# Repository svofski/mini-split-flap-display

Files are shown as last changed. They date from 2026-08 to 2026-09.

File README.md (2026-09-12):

# Mini Split-Flap Display

Video:

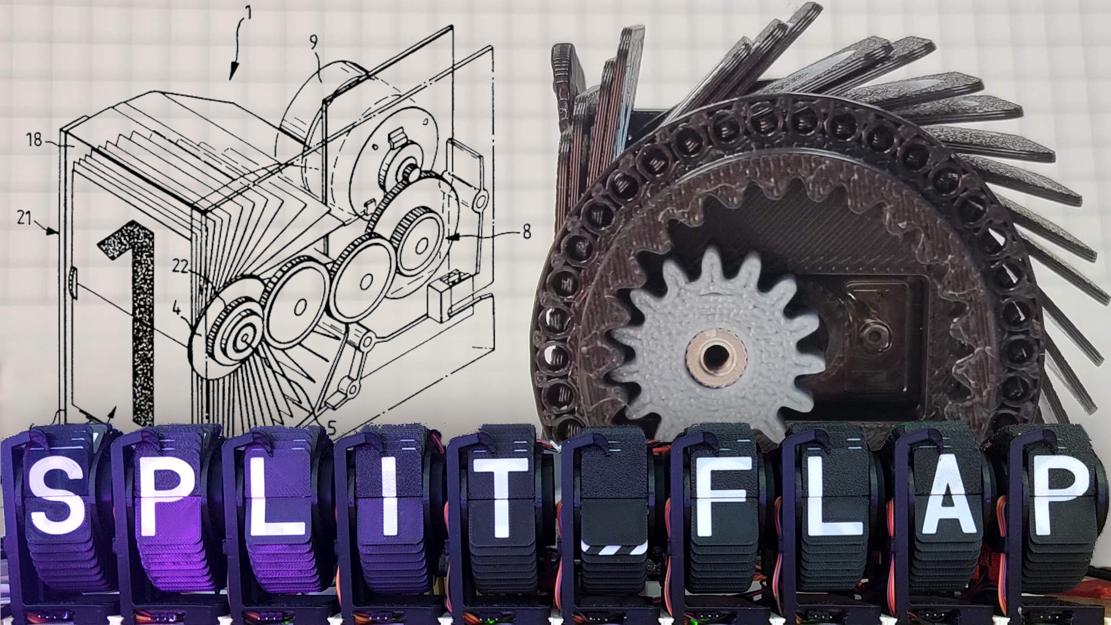
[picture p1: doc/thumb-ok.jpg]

https://www.youtube.com/watch?v=8y3peudQFPg

[Notes](doc/notes.txt), [printables](printables) and [CAD](printables/cad).

## Design goals

 * as compact as reasonably possible
 * full English alphabet and numbers, space and one extra character (38 flaps)
 * as cheap as reasonably possible, a bit janky is ok
 * 3D printable with minimal extra parts

The compact and cheap requirement limits the choice of motors to MG90S, or even SG90 micro servos. Steppers of similar size exist but they are a relative rarity and require a driver which costs more and takes space. Fortunately these motors can be bought in 360 degree variant.

## Approximate BOM

 * black and white PLA are mandatory for optical sensor contrast
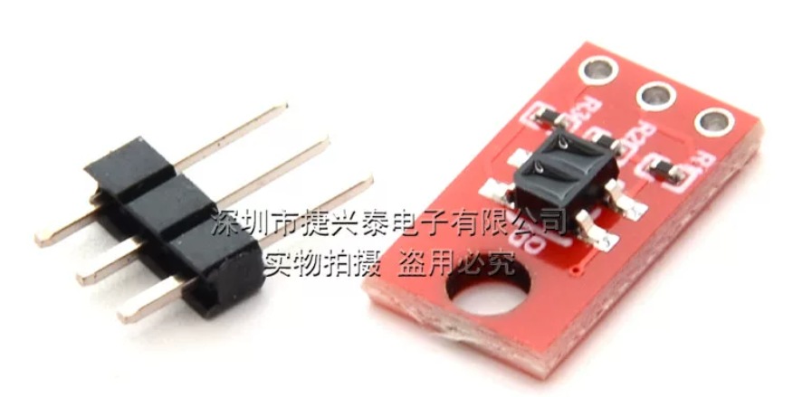
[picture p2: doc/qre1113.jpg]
qre1113
 * QRE1113 sensor module (1 per module, ￥1.89/pc)  (modules may require changing LED resistor to 330 ohm!)
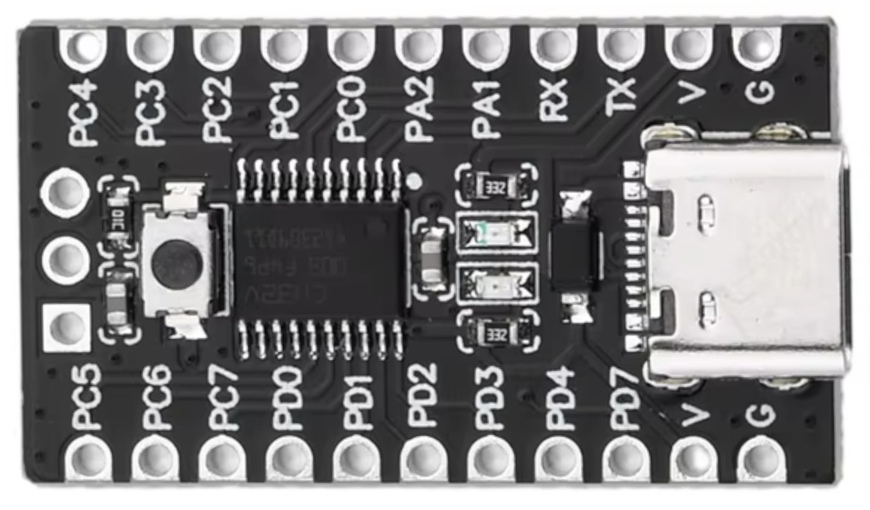
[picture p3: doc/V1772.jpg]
v1772
 * V1772 CH32V003F4P6 (1 per module, ￥2.86/pc) 
 * MG90S 360 degree servo (1 per module, ￥6.48/pc), SG90 360 degree can be used as well

## Design

See [printables](printables) and [CAD](printables/cad) for source files and detailed breakdown of every part.

The pictures tell everything. The motor is hidden inside the stator drum. Flappy drum sits on the stator driven by a little cog.
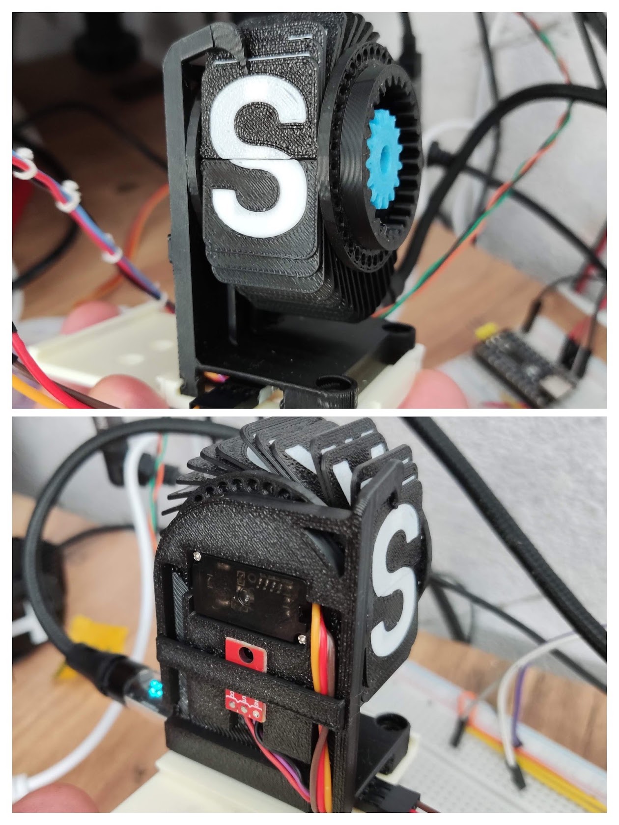
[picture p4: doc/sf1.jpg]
split-flap


The wires are relatively neatly tucked away in cable channels carved for them in the main post, held captive together with the sensor board with a little snap-fit bracket.
The MCU board is hidden in the foot. Some careful wire soldering is required during assembly which takes quite a long time.
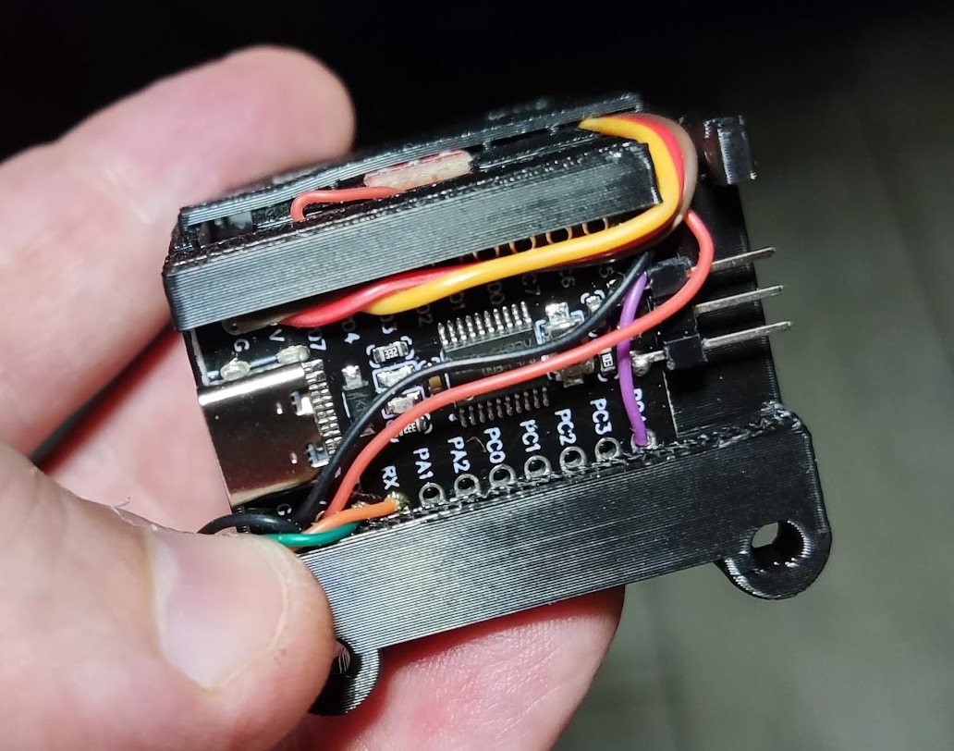
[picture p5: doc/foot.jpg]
feet pics


Because there are so many flaps in such a small place, precision positioning is important. The feedback is optical.
One of the sides of the flaps drum has embedded codewheel. Zero position is marked by a wider tick.
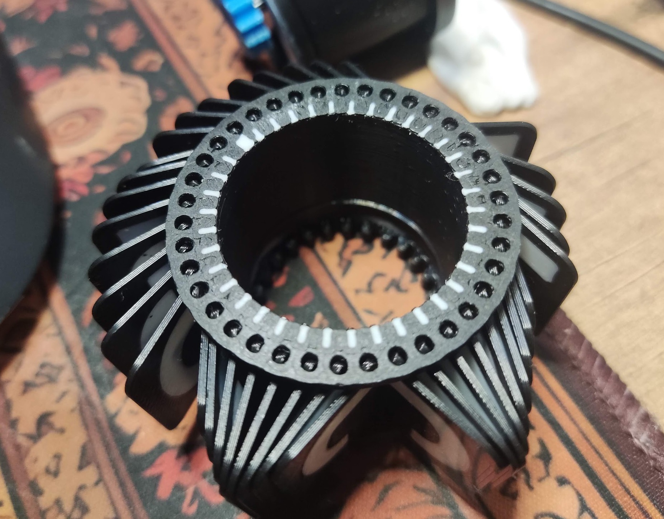
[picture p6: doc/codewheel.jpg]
codewheel


## Position sensing

Tracking reflective codewheel is not as trivial as I expected, sensor readout is far from ideal. Here's an example of what the readings look like:
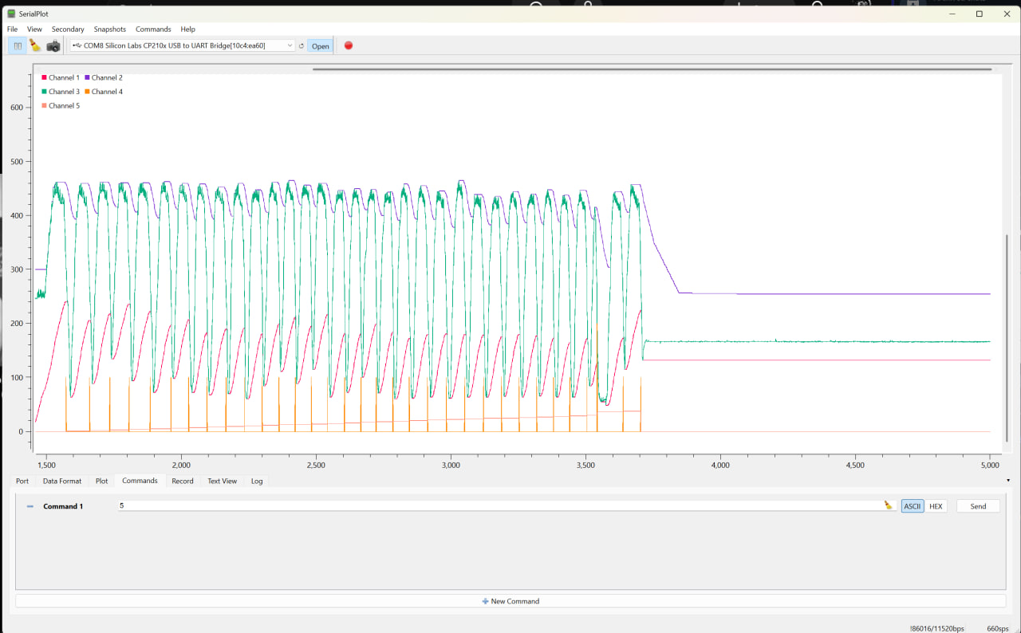
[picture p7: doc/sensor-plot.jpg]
sensor


The algorithm tracks min and max on raw data(green) independently (blue and red lines), then detects transitions over median line with added hysteresis.
High contrast here is very important. It's also important to print the code wheel side on a matte plate like Cool Plate SuperTack. Shiny tick marks read very poorly.

## Communications

Each wheel has independent controller (CH32V003). All together they are connected via I2C bus.

The master controller is Arduino Nano. In addition to requesting a letter display, the protocol supports setting I2C address and homing offset for every module.

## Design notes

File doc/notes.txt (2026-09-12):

Encoder sensor
~~~~~~~~~~~~~~
QRE1113 module 8x14.2mm, height ~3mm

Modifications for 5V operation

LED resistor: 330 ohm
collector resistor: 200K (maybe the default 100K is ok)

Split-Flap Controller
~~~~~~~~~~~~~~~~~~~~~
Controller board V1772, 5V MCU CH32V003F4P6

Schematic and notes: https://kyoichisato.github.io/ch32v003-getting-started-ja/V1772.html

Motors
~~~~~~
MG90S 360 degree version

Master MCU
~~~~~~~~~~
Arduino Nano 3 (5V)

Ideally same V1772 if both UART and I2C can be enabled at the same time. Definitely possible with ch32v003fun version, Arduino has too much fat.

Connections
~~~~~~~~~~~

Split-Flap module:

QRE1113 OUT -> CH32 PC4
MG90S PWM   -> CH32 PD3
I2C SDA	    -> CH32 PC1         -> Arduino Nano A4         -> 4K7 pullup to +5V      GREEN or BLUE
I2C SCL     -> CH32 PC2         -> Arduino Nano A5         -> 4K7 pullup to +5V      ORANGE

I2C Communication
~~~~~~~~~~~~~~~~~
Each split-flap display has its own address assigned at build/flashing time. Leftmost is 0x10, second to right is 0x11, etc.

EEPROM
~~~~~~

Reconfigurable parameters:

  - i2c address which must be unique for every display
  - zero mark offset (-4..-2 typically)
  - tracking divider, how fast min/max tracking decays

I2C Commands
~~~~~~~~~~~~

A-Z 0-9 - space	  display character
h                 home
q                 respond with "SFD" [addr] [homing offset] [position] [state] [tracking div]
z [n]             write new homing adjust, signed int8_t
r [n]             write new speed adjust, signed int8_t
d [n]             write new tracking divider (uint8_t), typically 64..110
a [addr] [~addr]  write new i2c addr, e.g.  0x61 0x11 0xee set addr = 0x11

Master controller (usb serial)
~~~~~~~~~~~~~~~~~~~~~~~~~~~~~~

Console commands: 

s               scan the bus, update internal structures and and print info about each display

p TEXT          type text on all units without power budgeting. guarranteed to fail if there are more than 2 units.

h               home all units with power budgeting

t TEXT          type text with power budgeting. text comprises [A-Z0-9\-] to display space use lowercase "h" (home), underscore to skip position

  t HELLO        type HELLO from current position  
  t _____X       update character in position 6 to X
  t h______      home display in position 1

Tuning commands

a addr          assign address. Only valid when there is a single display connected. Necessary when configuring a new module.
  a 0x11	set display i2c address = 0x11

z addr offset   set homing offset
  z 0x11 -3     display at 0x11 homes to position -3

d addr value    set envelope tracking divider (larger value means slower decay)
  d 0x11 110    set device 0x11 to track slower

r addr value    set speed offset. this value is multiplied by 8 and added to default speed programmed in display unit. the unit is microseconds/8.
  r 0x11 -10    add -80 to base speed

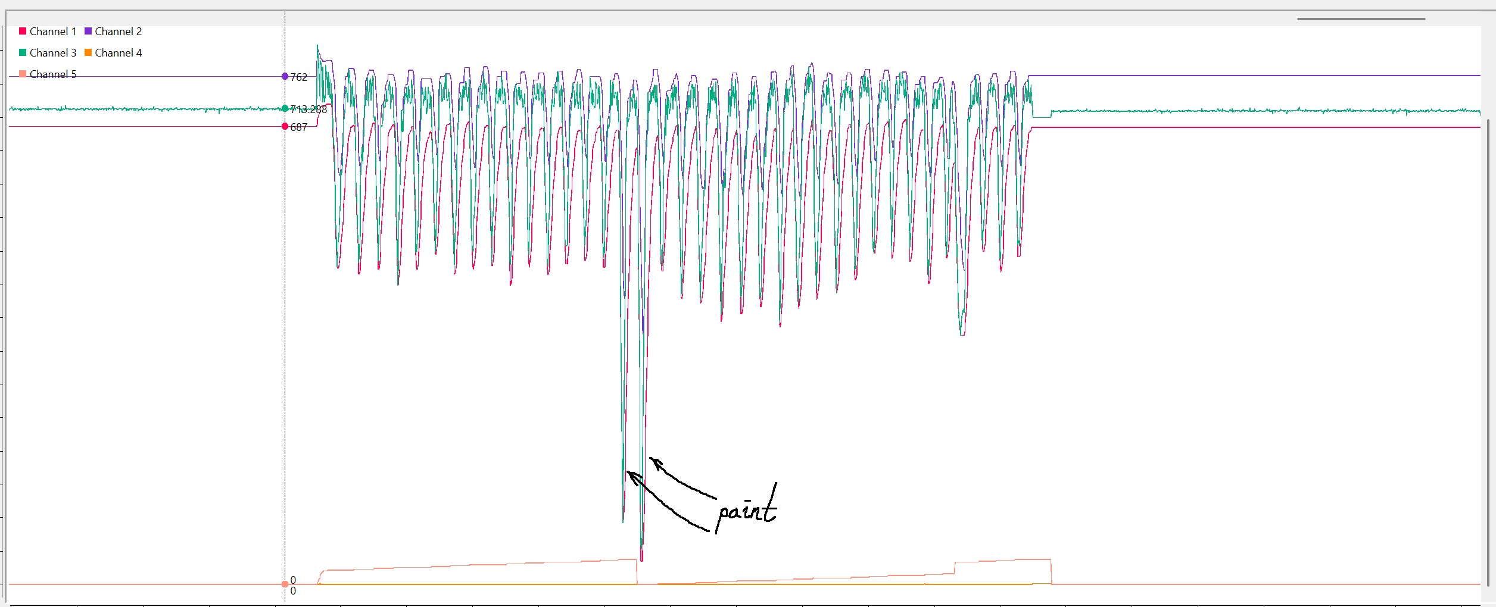
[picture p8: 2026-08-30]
doc/sensor-plot-white-paint.jpg

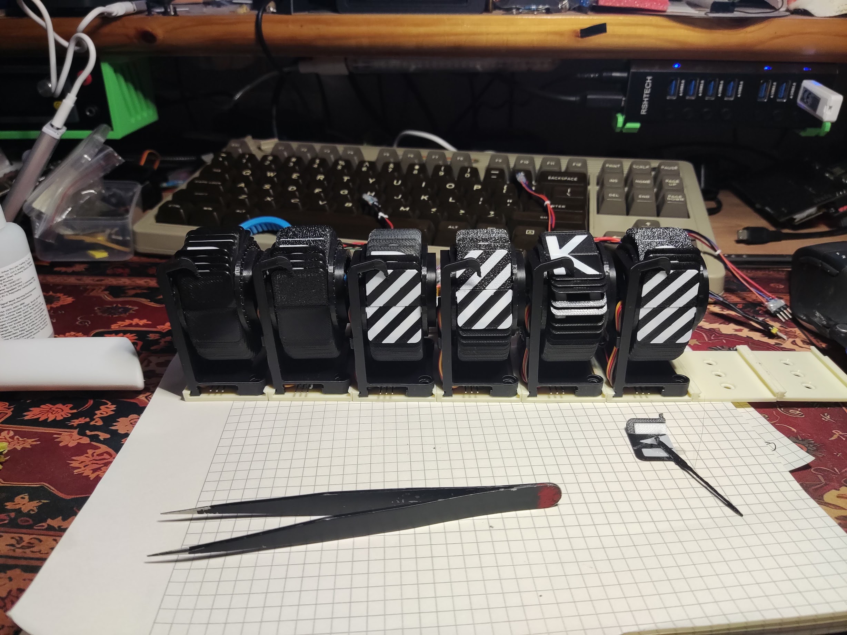
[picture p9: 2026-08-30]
doc/6pieces.jpg

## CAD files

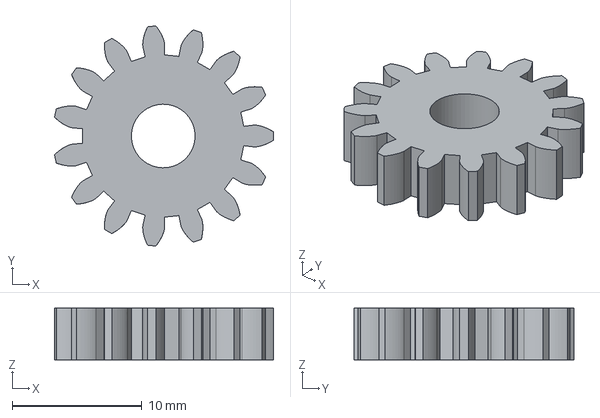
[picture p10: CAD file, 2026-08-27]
printables/cad/step/pinion.step
16.9 x 17.0 x 4.00 mm

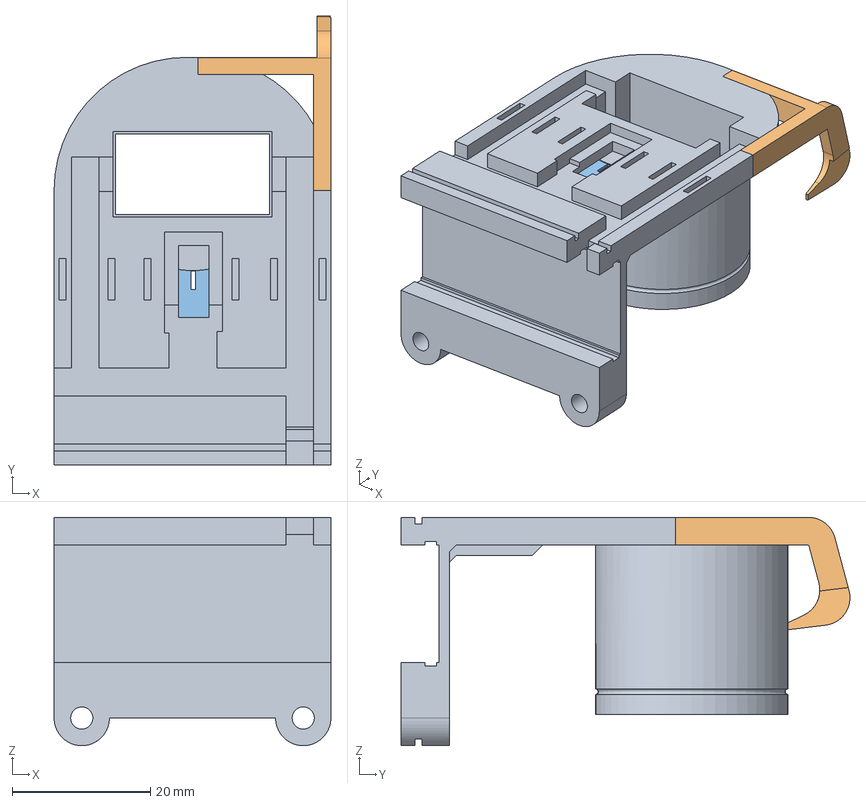
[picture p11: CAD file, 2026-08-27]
printables/cad/wheel-exp4-qre1113v3.FCStd
40.0 x 64.9 x 33.0 mm
Main
Finger
Aperture

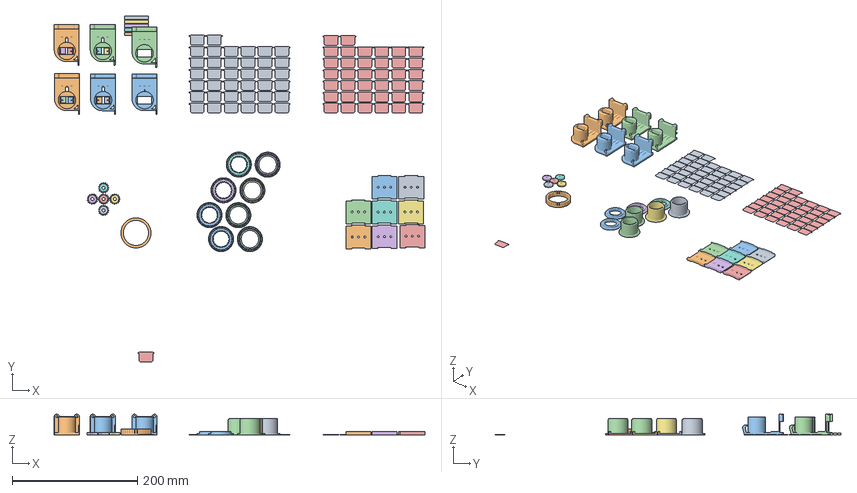
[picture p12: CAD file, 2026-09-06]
printables/split-flap-multiplate.3mf
591.3 x 551.9 x 33.0 mm
AssemblyJig
Assembly x 4
wheel-axle-markers-offset x 4
snappy-bracket.step x 5
stator_with_dovetail3.step x 2
rail.step x 8
pinion.step x 5
wheel-exp4-qre1113v3bis.step x 4
wheel-exp4-qre1113v3bis-aperture.step x 8

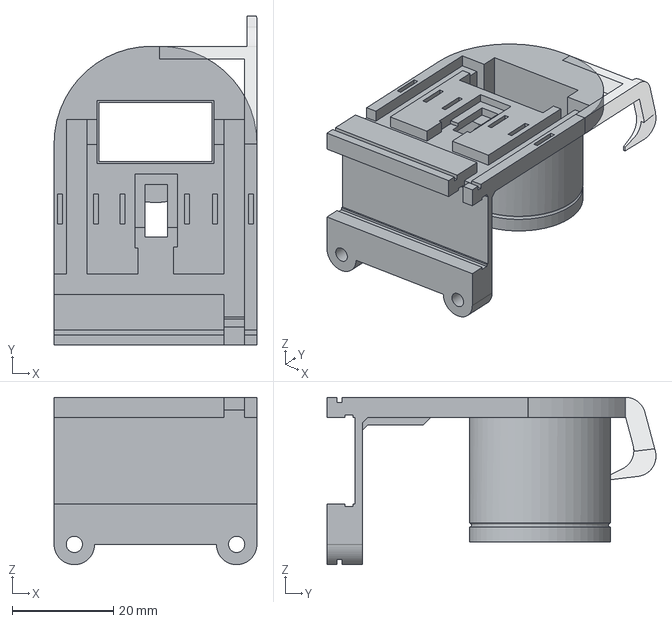
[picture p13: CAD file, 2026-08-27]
printables/cad/step/wheel-exp4-qre1113v3bis.step
40.0 x 64.9 x 33.0 mm
Main
Finger

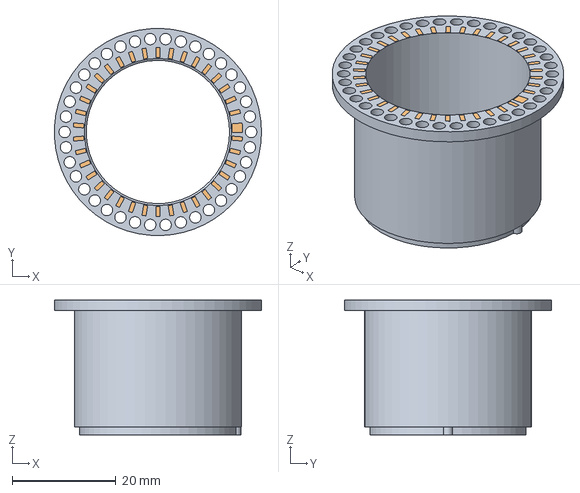
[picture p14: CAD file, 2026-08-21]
printables/cad/wheel-exp6.FCStd
40.0 x 40.0 x 26.0 mm
Wheel
MarkersWhite

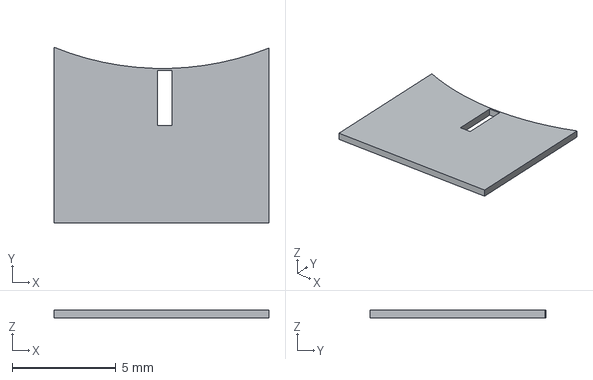
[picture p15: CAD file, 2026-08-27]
printables/cad/step/wheel-exp4-qre1113v3bis-aperture.step
10.4 x 8.48 x 0.4 mm

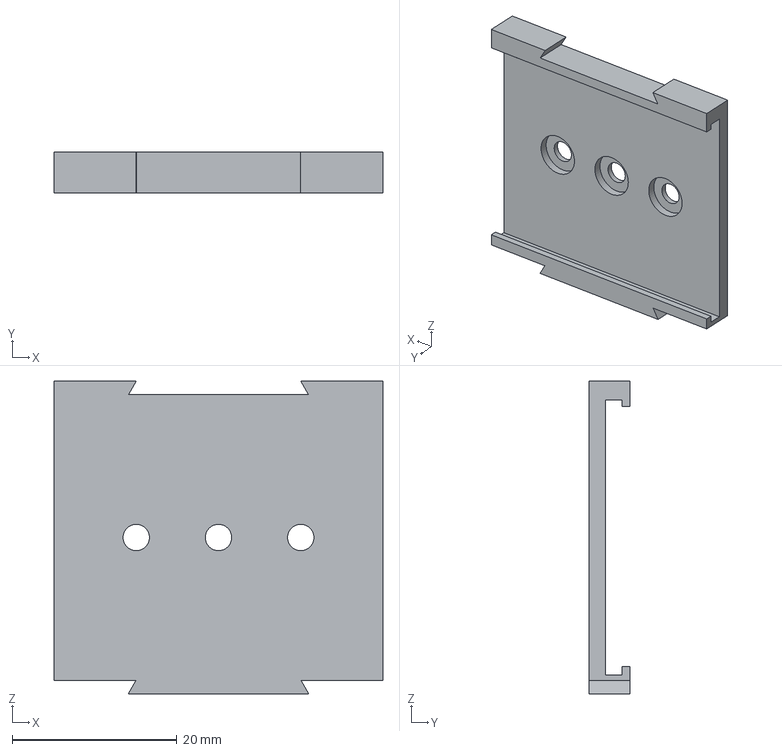
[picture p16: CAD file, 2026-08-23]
printables/cad/step/rail.step
40.0 x 5.00 x 38.0 mm

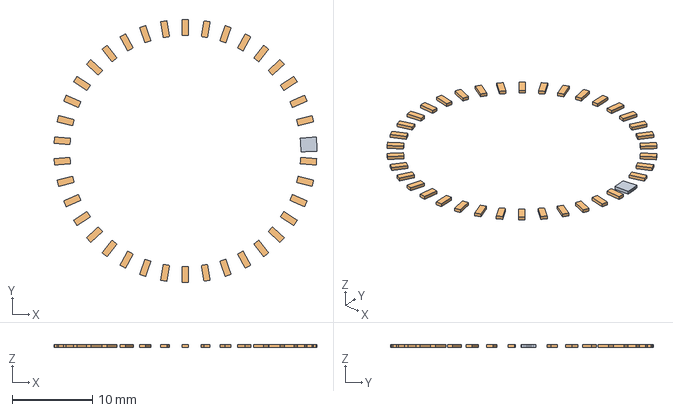
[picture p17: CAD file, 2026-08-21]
printables/cad/step/wheel-axle-markers-offset.step
32.7 x 32.7 x 0.4 mm

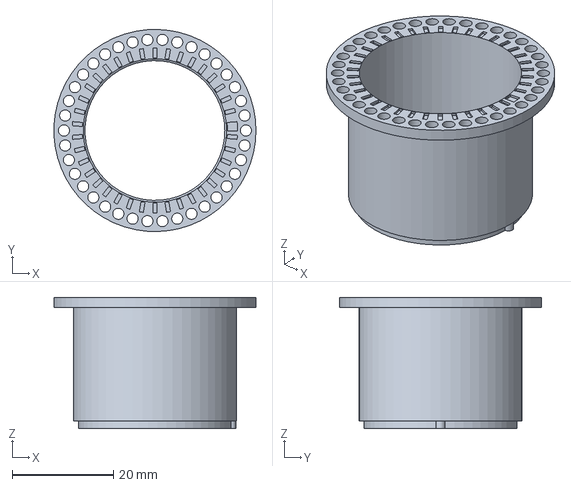
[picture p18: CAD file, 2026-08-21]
printables/cad/step/wheel-axle-offset.step
40.0 x 40.0 x 26.0 mm

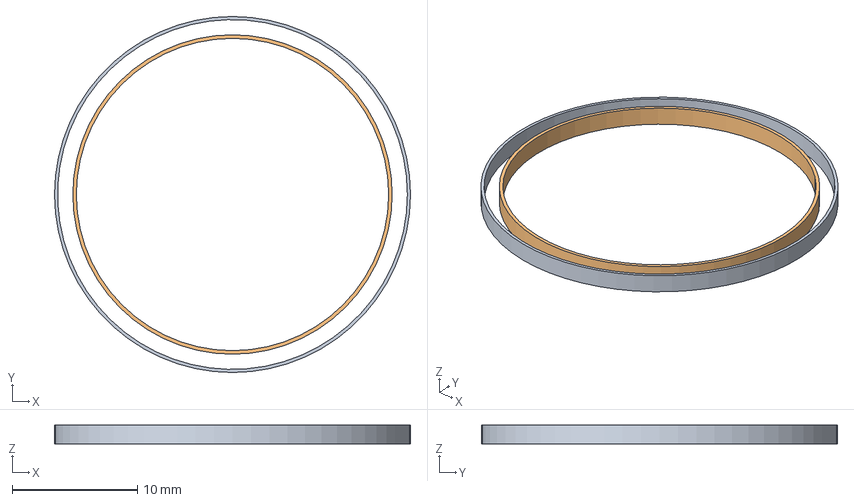
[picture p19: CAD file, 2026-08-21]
printables/cad/step/gear-support.step
28.4 x 28.4 x 1.48 mm

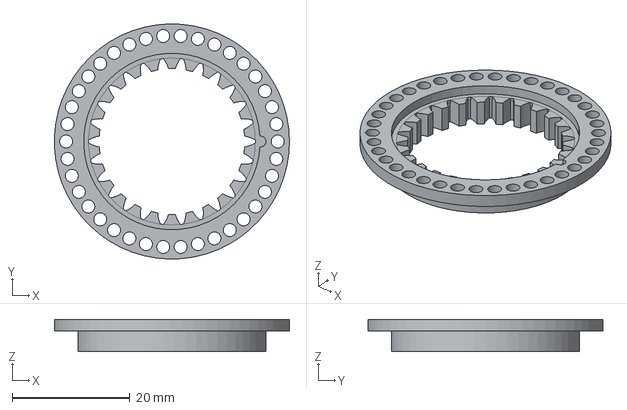
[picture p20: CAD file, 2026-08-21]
printables/cad/step/wheel-gear.step
40.0 x 40.0 x 5.51 mm

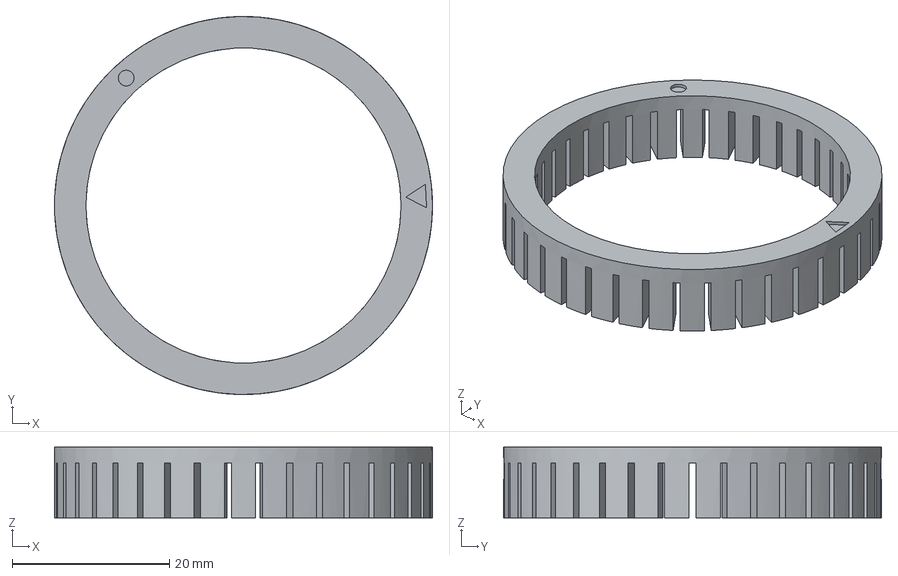
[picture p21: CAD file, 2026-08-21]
printables/cad/step/jig.step
48.0 x 48.0 x 9.00 mm

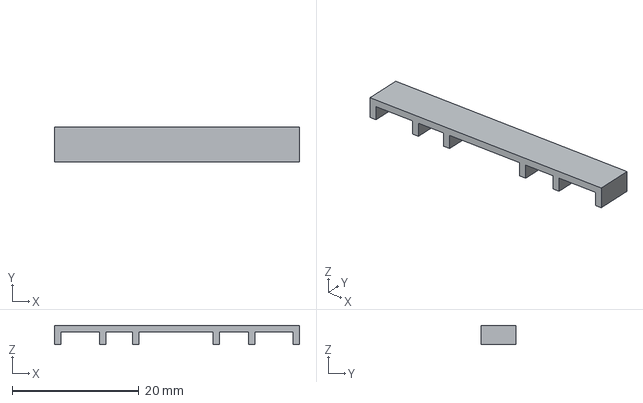
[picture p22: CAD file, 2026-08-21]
printables/cad/step/snappy-bracket.step
38.6 x 5.50 x 3.00 mm

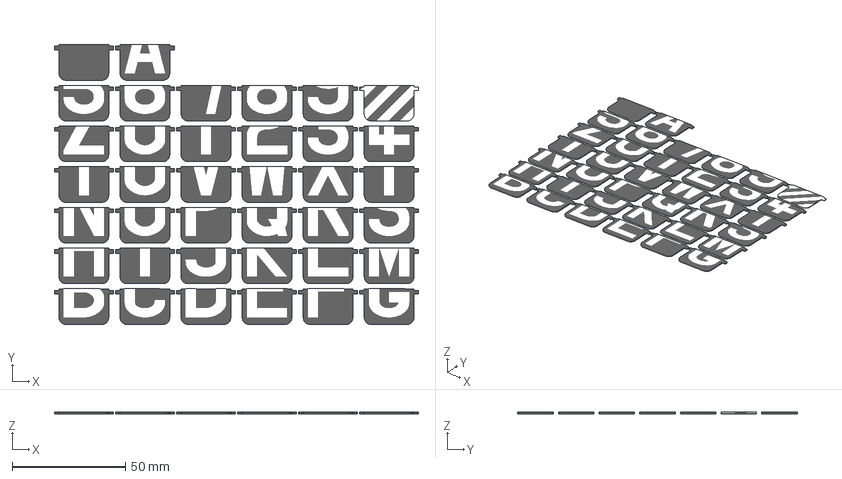
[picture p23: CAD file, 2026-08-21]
printables/cad/step/splitfap_with_barber_pole.3mf
161.0 x 123.8 x 0.82 mm

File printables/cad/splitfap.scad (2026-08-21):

// Final quality
render = false;

// Headlights are separate objects
separate_headlights = true;

// mode=0: generate everything
$fs = 0.4;//(render || mode >= 100) ? 0.5 : 1;

layer=0.2;

flap_width=22;
flap_height=16;
flap_thickness=0.8;
flap_gap=0.2;
font_size=22;
baseline=-15;
ear_len=2;
ear_offset=1.5; // ideal
barberpole_char="-";

use <Aston.ttf>;

eps=0.01;

chars="ABCDEFGHIJKLMNOPQRSTUVWXYZ0123456789- ";

letter_thickness = layer * 2;

all();

//glyph("A");
//barberpole();

module all()
{
    nline = floor(sqrt(len(chars)));
    xstep = (flap_width + 2*ear_len + 1);
    ystep = (flap_height + 2);
    for (i = [0:len(chars)-1]) {
        ch1 = chars[i];
        ch2 = chars[(i + 1) % len(chars)];
        translate([xstep * (i % nline), ystep * floor(i / nline), 0])
            colorflap(ch1, ch2);
    }
}

module colorflap(char1, char2) {
    color("black") oneflap(char1,char2, "flap");
    color("white") oneflap(char1,char2, "glyph");
}


module crop()
{
    intersection() {
        color("black") translate([0, -flap_height/2 - flap_gap, 0])
            cube([flap_width + ear_len*2, flap_height + eps*2, flap_thickness + eps*2], center = true);
        children(0);
    }
}

module oneflap(char1, char2, mode="flap")
{
    if (mode == "flap") {
        difference() {
            flap([flap_width,flap_height,flap_thickness], fillet_r=3);
            color("blue")
                crop()
                    translate([0,0,flap_thickness/2 - letter_thickness + eps])
                        glyph(char2);
            color("green") 
                crop()
                    translate([0,0,-flap_thickness/2 + letter_thickness - letter_thickness - eps])
                        scale([1,-1,1])
                            glyph(char1);
        }
    }
    else {
            color("blue")
                crop()
                    translate([0,0,flap_thickness/2 - letter_thickness + eps])
                        glyph(char2);
            color("green") 
                crop()
                    translate([0,0,-flap_thickness/2 + letter_thickness - letter_thickness - eps])
                        scale([1,-1,1])
                            glyph(char1);
    }
}

module glyph(letter)
{
    if (letter == barberpole_char) {
        barberpole();
    }
    else {
        linear_extrude(height=letter_thickness) 
            translate([0,baseline,0])
                text(letter, font="Aston:style=Regular", halign="center", valign="baseline", size=font_size);    
    }
}


module barberpole(pitch = font_size / 3)
{
    intersection() {
        union() {
            flap([flap_width,flap_height,flap_thickness], fillet_r=3);
            scale([1,-1,1]) flap([flap_width,flap_height,flap_thickness], fillet_r=3);
        }

        rotate([0,0,-45]) 
        translate([-font_size, -font_size, 0])
        for(i = [0:pitch:font_size * 2]) {
            translate([i, 0, 0]) 
                cube([pitch/2, font_size * 2, letter_thickness]);
        }
    }
}

module flap(sides, gap=flap_gap, ear_len=ear_len, ear_width=1.6, ear_offset=ear_offset, fillet_r = 3)
{
    hull() {
        translate([-sides.x/2 + fillet_r, -sides.y + fillet_r, 0])
            cylinder(h = sides.z, r = fillet_r, center = true);
        translate([+sides.x/2 - fillet_r, -sides.y + fillet_r, 0])
            cylinder(h = sides.z, r = fillet_r, center = true);
        
        translate([0,-gap*2,0])
        cube([sides.x, gap*2, sides.z], center = true);
    }
    
    
    translate([0, -(gap + ear_offset), 0])
    cube([sides.x + ear_len * 2, ear_width, sides.z], center = true);
    
}

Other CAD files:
printables/cad/step/stator_with_dovetail3-builtin-support.step
printables/cad/step/stator_with_dovetail3.step
printables/cad/step/splitfap.3mf

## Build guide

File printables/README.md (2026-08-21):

# Printables for Mini-Split-Flap Display

Large 3mf project with everything: [split-flap-multiplate.3mf](split-flap-multiplate.3mf)

CAD files, STEP files with commentary: [cad](cad)

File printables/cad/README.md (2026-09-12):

# CAD Files for Mini-Split-Flap Display

These files are a mess. I went through literally dozens of prototypes over multiple months with long breaks. 
I can't trace where the designs deviated. They should be merged into one but I don't know how to do it cleanly without breaking stuff.
So far there are just different CAD files. All current models also exist as .step and in one large .3mf project.

## [wheel-exp4-qre1113v3.FCStd](wheel-exp4-qre1113v3.FCStd) 

Stator 

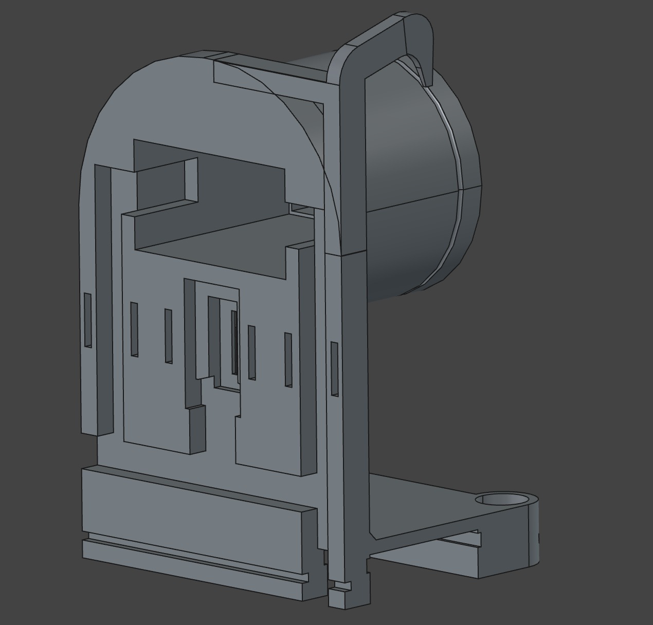
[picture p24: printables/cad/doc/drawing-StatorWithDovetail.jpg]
StatorWithDovetail


Single-print but needs supports under sensor aperture:
[stator_with_dovetail3.step](step/stator_with_dovetail3.step)

Wide sensor opening + glue-in aperture, my preferred version. If you have a matte build plate, print matte side towards the sensor (.3mf file assumes matte build plate, buttom looks towards the sensor).

[wheel-exp4-qre1113v3bis.step](step/wheel-exp4-qre1113v3bis.step)

[wheel-exp4-qre1113v3bis-aperture.step](step/wheel-exp4-qre1113v3bis-aperture.step)

Should have made the aperture thicker and more asymmetrical to make the orientation obvious.

Mounting rail

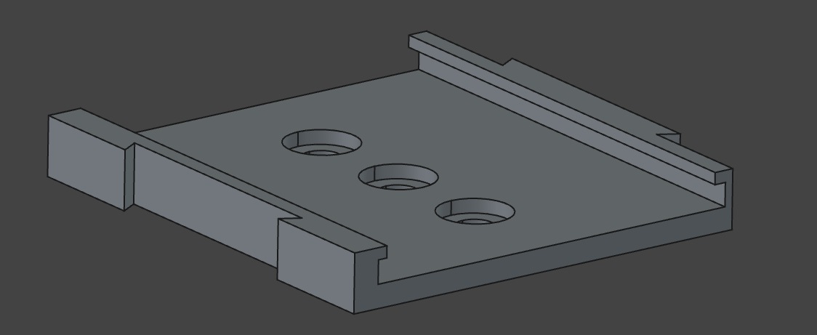
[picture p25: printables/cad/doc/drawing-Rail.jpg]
Rail


[rail.step](step/rail.step)

Snappy bracket (Body in StatorPart)

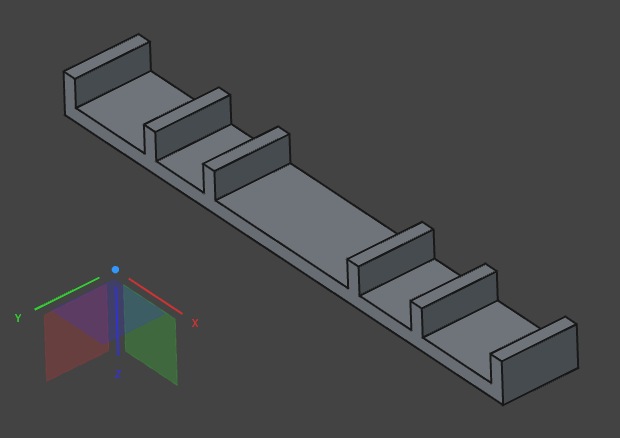
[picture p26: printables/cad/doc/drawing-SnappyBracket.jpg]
SnappyBracket


[snappy-bracket.step](step/snappy-bracket.step)

Pinion

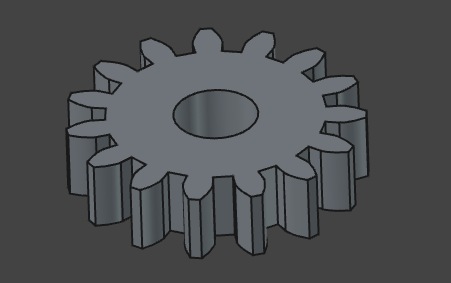
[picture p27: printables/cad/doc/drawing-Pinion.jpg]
Pinion


Step file missing. Refer to .3mf.

## [wheel-exp6.FCStd](wheel-exp6.FCStd) 

Wheel + MarkersWhite

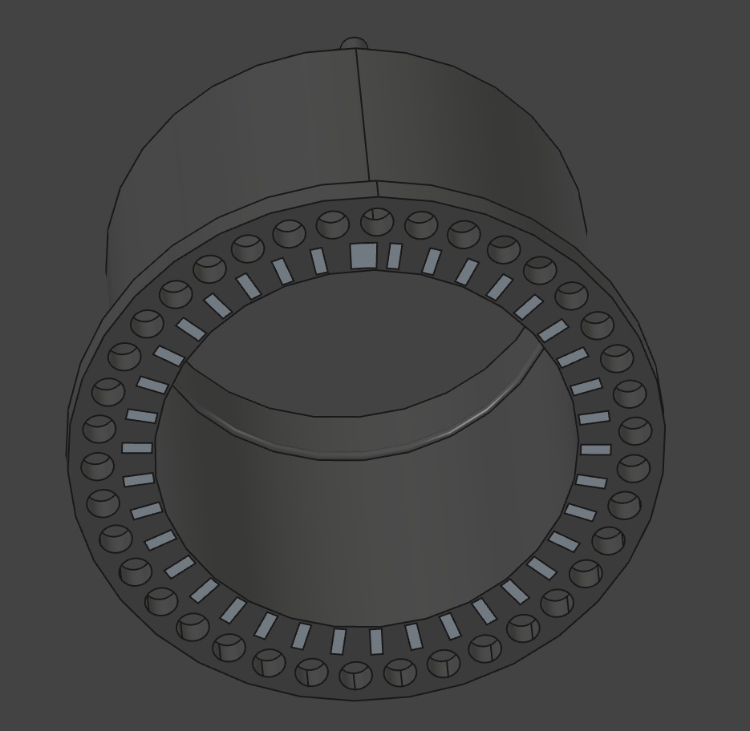
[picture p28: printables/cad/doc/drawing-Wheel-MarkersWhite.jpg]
Wheel+MarkersWhite


[wheel-axle-offset.step](step/wheel-axle-offset.step)

[wheel-axle-markers-offset.step](step/wheel-axle-markers-offset.step)

Note that the wheel + markers in wheel-exp4-qre1113v3.FCStd is lacking the wide marker.

Wheel2 (gear side)

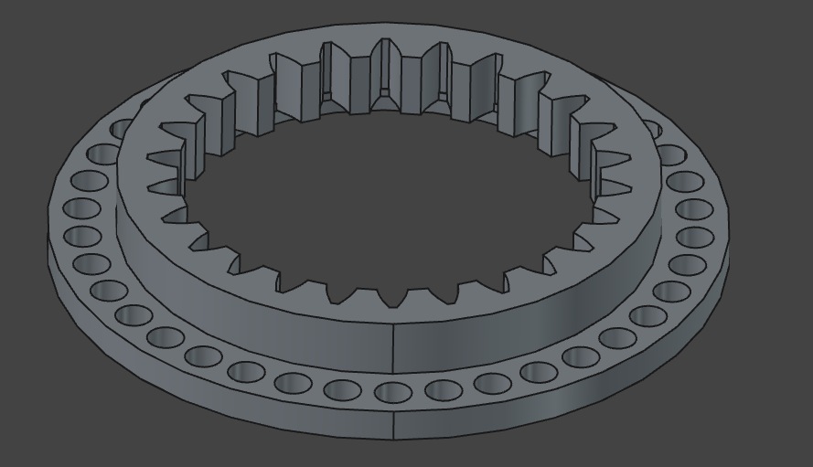
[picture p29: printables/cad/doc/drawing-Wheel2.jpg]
Wheel2


[wheel-gear.step](step/wheel-gear.step)

[gear-support.step](step/gear-support.step)

Assembly jig

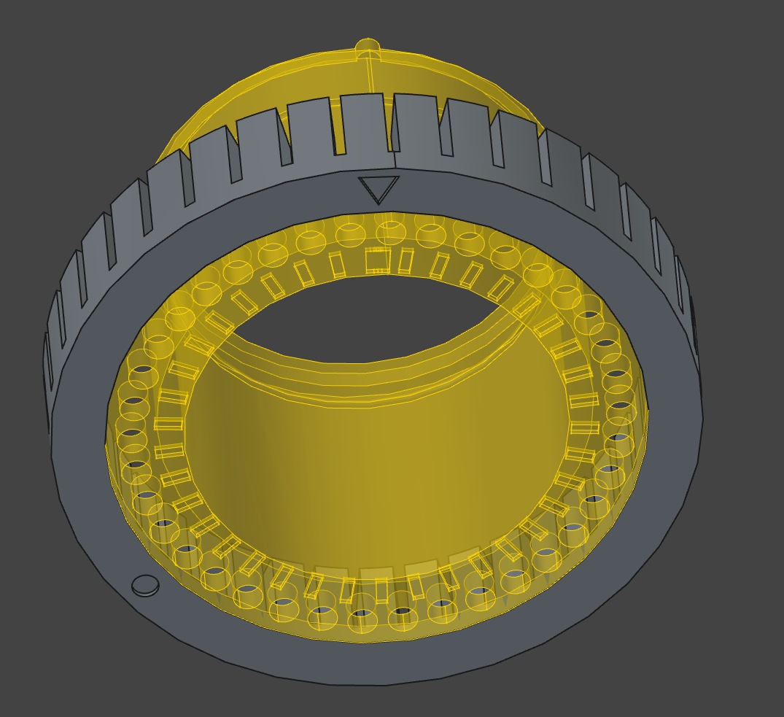
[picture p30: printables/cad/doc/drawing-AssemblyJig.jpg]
AssemblyJig


Step file missing. See .3mf.

## [splitfap.scad](splitfap.scad) OpenSCAD model for the flaps

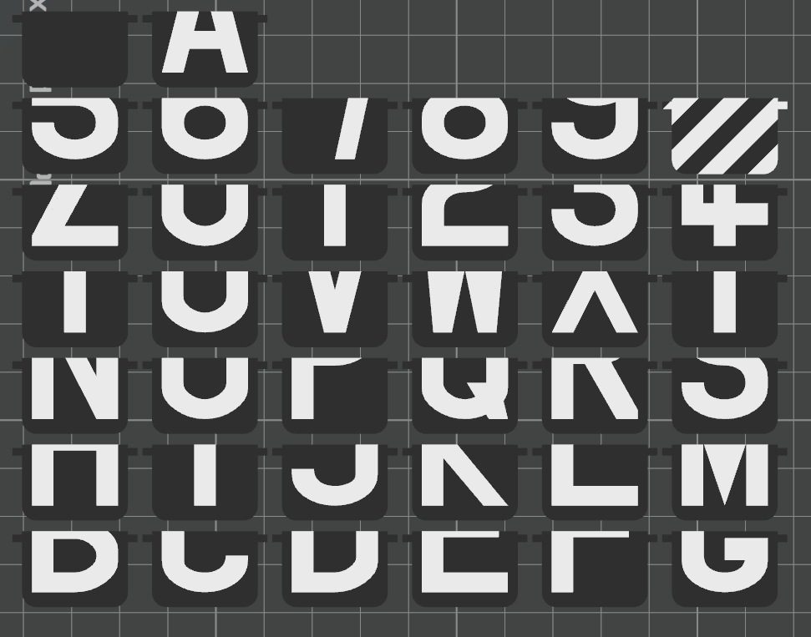
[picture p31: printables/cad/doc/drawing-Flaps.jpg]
Flaps


[splitfap.3mf](step/splitfap.3mf)

[splitfap_with_barberpole.3mf](step/splitfap_with_barberpole.3mf)

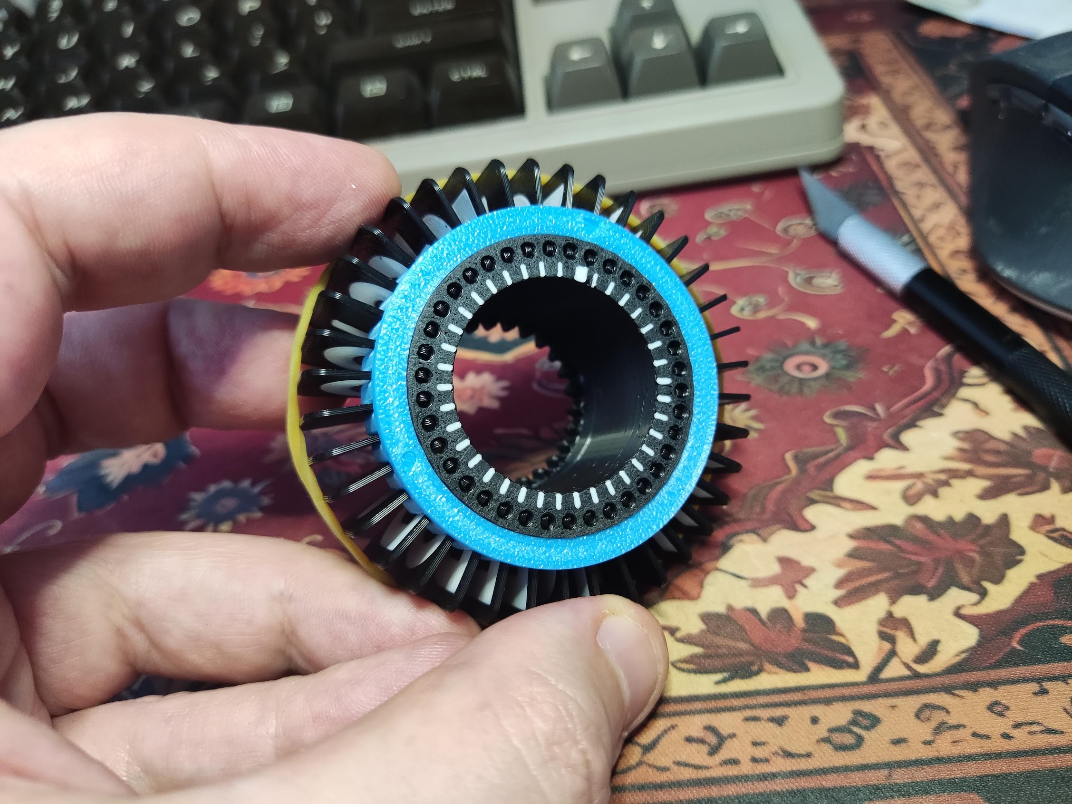
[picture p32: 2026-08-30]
doc/flaps-assembled-with-jig.jpg

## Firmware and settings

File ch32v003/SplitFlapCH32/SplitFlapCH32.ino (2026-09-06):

// qre1113 sensor board, the values of the resisors for 5V VCC are
// 330   LED cathode
// 200K  phototransistor collector
// 1K (default) output

// these options need configuration update in the package
// go to %USERHOME%\Documents\Arduino\hardware\ch32v\arduino_core_ch32\variants\CH32V00x\CH32V003F4\variant_CH32V003F4.h
// for SERIAL
//     #define                         UART_MODULE_ENABLED
// for I2C
//     #define                         I2C_MODULE_ENABLED
// 
//#define UART_MODULE_ENABLED 0
//#define I2C_MODULE_ENABLED 1


#include <Arduino.h>
#include <EEPROM.h>

#ifdef I2C_MODULE_ENABLED
#warning BUILDING I2C VERSION
#include <Wire.h>
#define DEFAULT_SLAVE_ADDR 0x10
#endif
#define DEFAULT_TRACKING_DIV 92  // 64 for faster reaction times
#define DEFAULT_HOMING_ADJUST (-2)
#define DEFAULT_SPEED_ADJUST_8 (0)

#define EEPROM_ADDR_CHECKSUM      0
#define EEPROM_ADDR_I2C_ADDR      1
#define EEPROM_ADDR_HOMING_ADJUST 2
#define EEPROM_ADDR_TRACKING_DIV  3
#define EEPROM_ADDR_SPEED_ADJUST  4
#define EEPROM_SIZE               5

#ifdef UART_MODULE_ENABLED
#warning BUILDING SERIAL VERSION
#endif

enum state_t {
    ST_IDLE = 0,
    ST_HOMING1,  
    ST_HOMING2,
    ST_HOMING3,
    ST_SEEK,
    ST_PAUSE,
    ST_PAUSE_RESTART
};

enum track_sensor_result_t { TS_IDLE, TS_PULSE, TS_MARKER };

constexpr int SERVO_PIN = PD3;
constexpr int SPEED_STOP = 180/2 - 2;

constexpr int SERVO_PULSE_MIN = 3276;
constexpr int SERVO_PULSE_MAX = 6553;

int16_t tracking_max = 300;
int16_t tracking_min = 0;
int16_t tracking_out = 0;

int16_t pulse_time = 0;
int16_t avg_pulse_time = 0;

constexpr int STEP_MILLIS = 1;
constexpr int INVERT = 1;

int8_t homing_skips = 0;
int8_t current_pos = 0;
int8_t seek_pos = 0;
state_t state = ST_IDLE;

uint8_t my_i2c_address = DEFAULT_SLAVE_ADDR;
int8_t  my_homing_adjust = DEFAULT_HOMING_ADJUST;
uint8_t tracking_div = DEFAULT_TRACKING_DIV; //64; //92 good for 0x11, 24 for 0x10 -- but 0x11 is not reliably switching single chars
int8_t speed_adjust_8 = DEFAULT_SPEED_ADJUST_8;

track_sensor_result_t track_sensor(int16_t x);
void eeprom_load_settings();
void eeprom_save_settings();

constexpr int SERVO_SPEED_1 = (SERVO_PULSE_MIN + SERVO_PULSE_MAX) / 2 + 1000;// 1000 is last known good

long start_time, prev_millis;

#ifdef I2C_MODULE_ENABLED
volatile int i2c_command;
volatile uint8_t i2c_acknowledge;

void sendDiagnostics();

static int8_t set_new_addr()
{
    uint8_t addr, naddr;

    if (Wire.available()) 
        addr = Wire.read();
    else
        return -1;
    if (Wire.available())
        naddr = Wire.read();
    else
        return -1;

    if (addr == static_cast<uint8_t>(~naddr)) {
        my_i2c_address = addr;
        eeprom_save_settings();
        Wire.end();
        Wire.begin(my_i2c_address);
        return 0;
    }

    return -1;
}

static int8_t set_new_adjust()
{
    if (Wire.available()) {
        my_homing_adjust = static_cast<int8_t>(Wire.read());
        eeprom_save_settings();
        return 0;
    }

    return -1;
}

static int8_t set_new_tracking_div()
{
    if (Wire.available()) {
        tracking_div = static_cast<uint8_t>(Wire.read());
        eeprom_save_settings();
        return 0;
    }

    return -1;
}

static int8_t set_new_speed()
{
    if (Wire.available()) {
        speed_adjust_8 = static_cast<int8_t>(Wire.read());
        eeprom_save_settings();
        return 0;
    }

    return -1;
}

static void onReceive(int num_bytes)
{
    (void)num_bytes;
    while(Wire.available()) {
        i2c_command = (uint8_t)Wire.read();
        switch (i2c_command) {
            case 'A'...'Z':
            case '0'...'9':
            case '-':
            case ' ':
                break;
            case 'q':
                i2c_acknowledge = 1;
                while (Wire.available()) Wire.read();
                return;
            case 'a': // set addr: new addr, new addr inverted
                set_new_addr();
                break;
            case 'z': // set homing adjust
                set_new_adjust();
                break;
            case 'd': // set tracking div
                set_new_tracking_div();
                break;
            case 'r': // set speed adjust
                set_new_speed();
                break;
        }
    }
}

static void onRequest(void)
{
    if (i2c_acknowledge) {
        i2c_acknowledge = 0;
        Wire.write("SFD");
        Wire.write(my_i2c_address);
        Wire.write((uint8_t)my_homing_adjust);
        Wire.write(current_pos);
        Wire.write(state);
        Wire.write(tracking_div);
        Wire.write((uint8_t)speed_adjust_8);
    }
    else {
        sendDiagnostics();
    }
}
#endif

void servo_start()
{
    analogWrite(SERVO_PIN, SERVO_SPEED_1 + speed_adjust_8 * 8);
}

void servo_stop()
{
    int8_t saved_pos = current_pos;
    // stopping reverse, doesn't really work 
    //analogWrite(SERVO_PIN, (SERVO_PULSE_MIN + SERVO_PULSE_MAX) / 2 - 200); 
    //delay(50);
    analogWrite(SERVO_PIN, (SERVO_PULSE_MIN + SERVO_PULSE_MAX) / 2); 
    delay(50);
    current_pos = saved_pos;
}

void eeprom_load_settings()
{
    uint8_t csum = 0;
    for (uint8_t adr = 1; adr < EEPROM_SIZE; ++adr) {
        csum += EEPROM[adr];
    }    
    if (csum == EEPROM[EEPROM_ADDR_CHECKSUM]) {
        my_i2c_address = EEPROM[EEPROM_ADDR_I2C_ADDR];
        my_homing_adjust = static_cast<int8_t>(EEPROM[EEPROM_ADDR_HOMING_ADJUST]);
        tracking_div = EEPROM[EEPROM_ADDR_TRACKING_DIV];
        speed_adjust_8 = EEPROM[EEPROM_ADDR_SPEED_ADJUST];
    }
}

void eeprom_save_settings()
{
    uint8_t csum = 0;
    csum += EEPROM[EEPROM_ADDR_I2C_ADDR] = my_i2c_address;
    csum += EEPROM[EEPROM_ADDR_HOMING_ADJUST] = static_cast<uint8_t>(my_homing_adjust);
    csum += EEPROM[EEPROM_ADDR_TRACKING_DIV] = tracking_div;
    csum += EEPROM[EEPROM_ADDR_SPEED_ADJUST] = speed_adjust_8;
    EEPROM[EEPROM_ADDR_CHECKSUM] = csum;
    EEPROM.commit();
}

void setup()
{
    my_i2c_address = DEFAULT_SLAVE_ADDR;
    my_homing_adjust = DEFAULT_HOMING_ADJUST;
    tracking_div = DEFAULT_TRACKING_DIV;
    EEPROM.begin();
    eeprom_load_settings();  

#ifdef UART_MODULE_ENABLED  
    Serial.begin(115200);
#endif  
    delay(3000);
#ifdef UART_MODULE_ENABLED  
    Serial.println("hello.jpg");
#endif  

#ifdef I2C_MODULE_ENABLED
    Wire.begin(my_i2c_address);
    Wire.onReceive(onReceive);
    Wire.onRequest(onRequest);
#endif

    pinMode(PD3, INPUT_PULLUP);

    pinMode(SERVO_PIN, OUTPUT);
    analogWriteFrequency(50);
    analogWriteResolution(16);
    servo_stop();
    prev_millis = start_time = millis();

    state = ST_PAUSE_RESTART;
    homing_skips = 20;

    i2c_acknowledge = 0;
    i2c_command = -1;
}

track_sensor_result_t track_sensor(int16_t x)
{
    track_sensor_result_t result = TS_IDLE;

    if (x > tracking_max) 
        tracking_max = x;
    else 
        tracking_max -= (tracking_max - x) / tracking_div;

    if (x < tracking_min)
        tracking_min = x;
    else
        tracking_min += (x - tracking_min) / tracking_div;

#ifdef UART_MODULE_ENABLED
    Serial.print(tracking_min); Serial.print(' '); Serial.print(tracking_max); Serial.print(' ');
#endif

    // set hysteresis threshold
    int16_t median = (tracking_min + tracking_max) / 2;
    int16_t thresh_low = median - 20;
    int16_t thresh_high = median + 20;

    int16_t prev_tracking_out = tracking_out;
    if (tracking_out == 0 && x > thresh_high) {
        tracking_out = 1;
    }
    else if (tracking_out != 0 && x < thresh_low) {
        tracking_out = 0;
    }

    if (prev_tracking_out != INVERT && tracking_out == INVERT) {
        pulse_time = 0;
    }
    else if (tracking_out == INVERT) {
        pulse_time += 1;
    }
    else if (prev_tracking_out == INVERT && tracking_out != INVERT) {
        avg_pulse_time = (3 * avg_pulse_time + pulse_time) / 4;
        if (INVERT == 0) {
            int thresh = avg_pulse_time * 13 / 8; //7 / 4; //5 / 3;
            result = TS_PULSE;
            if (pulse_time > thresh) {
                result = TS_MARKER;
            }
        }
        else {
            int thresh = avg_pulse_time * 2 / 3;
            result = TS_PULSE;
            if (pulse_time <= thresh) {
                result = TS_MARKER;
            }
        }
    }

    return result;
}

#ifdef I2C_MODULE_ENABLED
struct diags_buf_t {
    int16_t tracking_min, tracking_max;
    int16_t sensor_value;
    track_sensor_result_t ts;
    int8_t current_pos;
} __attribute__((packed));

static diags_buf_t diags[2];
uint8_t diags_wr_index = 0;

void updateDiagnostics(int16_t sensor_value, track_sensor_result_t ts)
{
    diags[diags_wr_index].tracking_min = tracking_min;
    diags[diags_wr_index].tracking_max = tracking_max;
    diags[diags_wr_index].sensor_value = sensor_value;
    diags[diags_wr_index].ts = ts;
    diags[diags_wr_index].current_pos = current_pos;
}

void wire_write_i16(int16_t value)
{
    Wire.write((uint8_t) (value & 0xff));
    Wire.write((uint8_t) ((value >> 8) & 0xff));
}

void sendDiagnostics()
{
    //uint8_t rdidx = diags_wr_index ^ 1;
    uint8_t rdidx = 0;
    Wire.write(0xde | rdidx); 
    wire_write_i16(diags[rdidx].tracking_min);
    wire_write_i16(diags[rdidx].tracking_max);
    wire_write_i16(diags[rdidx].sensor_value);
    Wire.write((uint8_t)diags[rdidx].ts);
    Wire.write((int8_t)diags[rdidx].current_pos);
    Wire.write(0xad | rdidx);
    //diags_wr_index = rdidx;
}
#endif

void loop() {
    long now = millis();
    if (1 || now - prev_millis > STEP_MILLIS) {
        int c;
#ifdef UART_MODULE_ENABLED
        c = Serial.read();
#endif
#ifdef I2C_MODULE_ENABLED
        c = i2c_command;
        i2c_command = -1;
#endif
        if (c == 'h') {
            state = ST_HOMING1;
            homing_skips = 20;
            servo_start();
        }
        else if ((c >= 'A' && c <= 'Z') || (c >= '0' && c <= '9') || c == '-') {
            int pos = -1;

            if (c >= 'A' && c <= 'Z') {
                pos = c - 'A' + 1;
            }
            else if (c >= '0' && c <= '9') {
                pos = 27 + (c - '0');
            }
            else if (c == '-') {
                pos = 37;
            }

            state = ST_SEEK;
            servo_start();      
            seek_pos = pos;
        }

        prev_millis = now;
        int sensorValue1 = analogRead(A2);
        track_sensor_result_t ts = TS_IDLE;
        if (state != ST_PAUSE_RESTART) {
            ts = track_sensor(sensorValue1);    
        }
#ifdef UART_MODULE_ENABLED
        Serial.print(sensorValue1); Serial.print(' '); Serial.print(ts * 100); Serial.print(' '); Serial.println(current_pos);
#endif
#ifdef I2C_MODULE_ENABLED
        updateDiagnostics(sensorValue1, ts);
#endif

        switch (ts) {
            case TS_MARKER:
                if (state == ST_HOMING2) {
                    current_pos = my_homing_adjust + 38;
                    seek_pos = 0;
                    state = ST_SEEK;
                }
                else {
                    current_pos = (current_pos + 1) % 38;
                }

                if (state == ST_SEEK && seek_pos == current_pos) {
                    servo_stop();
                    state = ST_PAUSE_RESTART;
                    start_time = now;
                }
                break;
            case TS_PULSE:
                current_pos = (current_pos + 1) % 38;
                if (state == ST_HOMING1) {
                    if (homing_skips > 0) {
                        if (--homing_skips == 0) state = ST_HOMING2;
                    }
                }
                if (state == ST_SEEK) {
                    if (current_pos == seek_pos) {
                        servo_stop();
                        //state = ST_IDLE;
                        state = ST_PAUSE_RESTART;
                        start_time = now;
                    }
                }
                break;
            case TS_IDLE:
            default:
                break;
        }
    }
}
/* vim: set filetype=cpp: */

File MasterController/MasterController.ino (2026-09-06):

#include <Wire.h>
#include <errno.h>
#include "SerialCommand.h" // SerialCommand by Steven Cogswell and Stefan Rado

#define MAX_SPLIT_FLAPS 16

SerialCommand cmd;

uint8_t splitflaps[MAX_SPLIT_FLAPS] {};
uint8_t n_splitflaps = 0;

uint8_t budget_homing = 10;
uint8_t budget_typing = 10;

// Console commands: 

// t HELLO         type HELLO from line start
// a addr          assign address (only valid when there is a single display connected)
//   a 0x11	set display i2c address = 0x11
// z addr offset   set homing offset
//   z 0x11 3      display at 0x11 homes to position 3
// d addr div      set tracking divider
// 1 0x13 A        send 'A' to addr 0x13
// r addr n        speed adjust, add n * 8 us to pulse time (signed byte)

static uint8_t response_buf[16];

// print buffer
static char text[MAX_SPLIT_FLAPS + 1];

void printhex(uint8_t val)
{
    if (val < 16) Serial.print('0');
    Serial.print(val, 16);
}

void hexdump(const uint8_t * buf, uint8_t len)
{
    for (uint16_t i = 0; i < len; ++i) {
        printhex(buf[i]);
        Serial.print(' ');
    }
}

// return state or -1 if error
int8_t check_display(uint8_t addr, bool verbose=true, bool save=false)
{
    Wire.beginTransmission(addr);
    Wire.write('q');
    Wire.endTransmission();

    static constexpr uint8_t status_sz = 9;

    Wire.requestFrom((uint8_t)addr, status_sz); // expect response S F D aa zz pp ss tt rr

    uint8_t i = 0;
    while (Wire.available() && i < sizeof(response_buf)) {
        response_buf[i++] = Wire.read();
    }

    //if (verbose) hexdump(response_buf, i);

    if (i < status_sz) {
        return -1;
    }
    if (memcmp_P(response_buf, PSTR("SFD"), 3) == 0) {
        uint8_t addr = response_buf[3];
        int8_t zero = static_cast<int8_t>(response_buf[4]);
        uint8_t pos = response_buf[5];
        uint8_t state = response_buf[6];
        uint8_t tracking_div = response_buf[7];
        int16_t speed_adj = static_cast<int8_t>(response_buf[8]);
        if (verbose) {
            Serial.print(F("SFD 0x")); Serial.print(addr, 16); 
            Serial.print(F(" home:"));
            if (zero >= 0) Serial.print('+'); Serial.print(zero, 10); 
            Serial.print(F(" pos:")); Serial.print(pos);
            Serial.print(F(" state:")); Serial.print(state);
            Serial.print(F(" div:")); Serial.print(tracking_div);
            Serial.print(F(" speed:")); Serial.print(speed_adj * 8);
        }

        if (save) {
            if (n_splitflaps >= MAX_SPLIT_FLAPS) {
                return -1;
            }
            else {
                splitflaps[n_splitflaps] = addr;
                ++n_splitflaps;
            }
        }

        return state;

    }

    return -1;
}

int8_t wait_for_idle(uint8_t addr)
{
    int8_t result;
    do {
        result = check_display(addr, false, false);
    } while (result >= 0 && (result != 6) && (result != 0));

    return result;
}

int8_t count_busy_units()
{
    int8_t count = 0;
    for (uint8_t i = 0; i < n_splitflaps; ++i) {
        if (check_display(splitflaps[i], false, false) != 6) ++count;
    }

    return count;
}

void wait_budget(uint8_t budget)
{
    uint8_t n_busy;
    do {
        n_busy = count_busy_units();
        delay(10);
    } while (n_busy >= budget);
}

void scan_i2c()
{
    memset(splitflaps, 0, sizeof(splitflaps));
    n_splitflaps = 0;

    Serial.println(F("Scanning..."));
    int nDevices = 0;
    for (byte address = 1; address < 127; ++address) {
        // The i2c_scanner uses the return value of
        // the Wire.endTransmission to see if
        // a device did acknowledge to the address.
        Wire.beginTransmission(address);
        byte error = Wire.endTransmission();

        if (error == 0) {
            if (check_display(address, true, true) < 0) {
                Serial.print(F(" ERROR"));
            }

            Serial.println();

            ++nDevices;
        } 
        else if (error == 4) {
            Serial.print(F("Unknown error at address 0x"));
            if (address < 16) {
                Serial.print('0');
            }
            Serial.println(address, HEX);
        }
    }
    if (nDevices == 0) {
        Serial.println(F("No I2C devices found\n"));
    }

    Serial.print(F("Found ")); Serial.print(n_splitflaps);
    Serial.print(F(" split-flap displays: "));
    hexdump(splitflaps, n_splitflaps);
    Serial.println();
}

void sendAck()
{
    Serial.println(F("OK"));
}

void sendNak()
{
    Serial.println(F("ERROR"));
}

void send_to_display(uint8_t addr, char ch)
{
    Wire.beginTransmission(addr);
    Wire.write(ch);
    Wire.endTransmission();
}

void cmdSingleChar()
{
    const char *arg = cmd.next();
    uint8_t addr = 255;

    errno = 0;
    int valor = strtol(arg, nullptr, 0);
    if (errno == 0 && valor > 0 && valor < 128) {
        addr = valor;
    }
    if (addr == 255) return;

    arg = cmd.next();
    if (arg == nullptr) return;

    send_to_display(addr, *arg);    
}

void print_text(const char *arg)
{
    uint8_t len = min(strlen(arg), n_splitflaps);

    char msg[MAX_SPLIT_FLAPS];
    memcpy(&msg[0], arg, len);

    int8_t remains = (int8_t)len;

    do {
        for (uint8_t i = 0; i < len; ++i) {
            uint8_t c = msg[i];
            if (c == 0)
                continue;

            wait_budget(budget_typing);
            switch (c) {
                case 'A'...'Z':
                case '0'...'9':
                case '-':
                case ' ':
                case 'h':
                    send_to_display(splitflaps[i], c);
                    break;
                default:
                    break;
            }
            msg[i] = 0;
            --remains;
        }
    } while (remains > 0);
}

// build text[] buffer from multiple args and return length
int8_t prepare_text(const char * first)
{
    uint8_t pos = 0;

    while(1) {
        const char *arg = first ? first : cmd.next();
        first = nullptr;
        if (arg == nullptr) break;
        if (pos > 0) {
            text[pos++] = '_';
        }
        for (uint8_t n = 0; (pos < MAX_SPLIT_FLAPS) && (arg[n] != 0); ++pos, ++n) {
            text[pos] = arg[n];
        }
    }
    text[pos] = 0;

    return pos;
}

void cmdType()
{
    if (prepare_text(nullptr) == 0) {
        sendNak();
        return;
    }
    print_text(text);
    sendAck();    
}

void cmdPrintDefault(const char *cmd)
{
    if (prepare_text(cmd) == 0) {
        sendNak();
        return;
    }
    cmdHome();
    print_text(text);
}
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

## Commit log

2026-08-21 sensor plot
2026-08-21 cad files + readme
    [wheel-exp4-qre1113v3.FCStd, wheel-exp6.FCStd]
2026-08-21 partial step files
    [jig.step, rail.step, snappy-bracket.step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]
2026-08-21 more step files
    [gear-support.step, wheel-axle-markers-offset.step, wheel-axle-offset.step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]
2026-08-21 3mf update, splitfap.scad
    [split-flap-multiplate.3mf, splitfap.scad]
2026-08-21 formatting, font files
    [wheel-exp6.FCStd]
2026-08-27 updated cad files
    + pinion.step with slightly enlarged axle hole for easier fit
    + wheel-exp4-qre1113v3bis, aperture is the new attempt at making the
    aperture easy to print and reliable. it's a two-part print now but it
    seems to be coming together better than removing supports from under a
    precision section of the part
    + builtin-support still in the files just in case but i think it's over
    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
    [pinion.step, split-flap-multiplate.3mf, stator_with_dovetail3-builtin-support.step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]
2026-08-30 updated 3mf
    [split-flap-multiplate.3mf]
2026-09-03 power budgeting and notes
    [split-flap-multiplate.3mf]
2026-09-06 implemented speed adjust tunable param
    r 0x10 adj (signed, will be multiplied by 8)
    [split-flap-multiplate.3mf]
